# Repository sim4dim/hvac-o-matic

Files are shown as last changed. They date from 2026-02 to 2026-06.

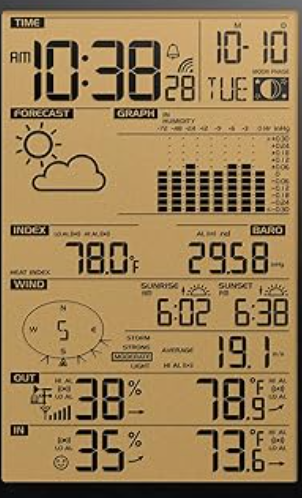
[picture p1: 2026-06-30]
screenshots/2026-05-18T20-38-01-354Z-Screenshot_2026-05-18_at_4.37.25_PM.png

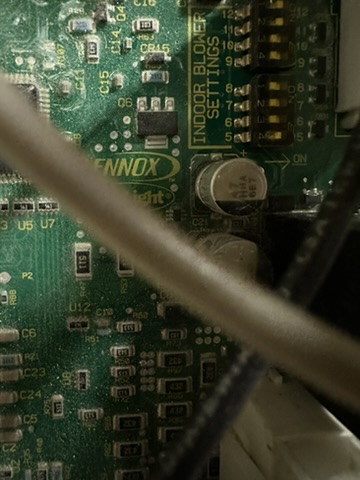
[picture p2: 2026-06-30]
screenshots/2026-06-29T21-41-32-357Z-4EC95CB4-6879-451B-B8CF-8DA977CA0F62_4_5005_c.jpeg

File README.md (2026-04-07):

# Keenect — Smart HVAC Zone Control

<!-- TODO: Add badges (HA version, ESPHome version, license) -->

Add per-room temperature control to a standard single-zone forced-air furnace using Keen Smart Vents, an ESP32 furnace controller, and Home Assistant automation logic. No HVAC contractor required.

<!-- TODO: Add screenshots -->

---

## Table of Contents

1. [Overview](#overview)
2. [System Architecture](#system-architecture)
3. [Hardware Requirements](#hardware-requirements)
4. [Software Requirements](#software-requirements)
5. [How It Works](#how-it-works)
6. [Safety Design](#safety-design)
7. [Installation](#installation)
8. [Configuration](#configuration)
9. [Project Structure](#project-structure)
10. [Legacy / History](#legacy--history)
11. [Contributing](#contributing)
12. [License](#license)

---

## Overview

Most homes have a single-zone forced-air HVAC system: one thermostat controls the whole house. Rooms with more sun exposure, different insulation, or different occupancy patterns are always too hot or too cold.

Keenect solves this by adding per-room temperature setpoints on top of your existing system without replacing the furnace or ductwork:

- **Keen Smart Vents** (Zigbee motorized dampers) control airflow into each room proportionally based on how far that room is from its setpoint.
- **An ESP32-S3 controller** with a relay board takes over from your wall thermostat to run the furnace only when one or more zones demand it.
- **Home Assistant** runs the control loop, calculates demand across all zones, and coordinates everything.
- A **hardware bypass** ensures your original thermostat retakes control if anything fails.

The system currently controls four zones (master bedroom, two kids' rooms, first floor) with additional passive temperature monitoring in other rooms.

---

## System Architecture

```
┌─────────────┐     Zigbee      ┌──────────────┐
│ Keen Vents  │◄───────────────►│ Zigbee Hub   │
│ (per room)  │                 │ (Hubitat C-8)│
└─────────────┘                 └──────┬───────┘
                                       │ Integration
┌─────────────┐     ESPHome API  ┌─────┴────────┐     MQTT        ┌──────────────┐
│ 1st Floor   │◄────────────────►│              │───heartbeat────►│ ESP32-S3     │
│ Servo (ESP32)│                 │ Home         │                 │ HVAC         │
└─────────────┘                 │ Assistant    │                 │ Controller   │
                                │              │                 │              │
┌─────────────┐                 │ Pyscript:    │                 │ 8ch Relay    │
│ Thermostats │◄───────────────►│ keenect_ha   │                 │ Board        │
│ (HA climate)│  climate_tmpl   │              │                 └──────┬───────┘
└─────────────┘                 └──────────────┘                        │ 24VAC
                                                                 ┌──────┴───────┐
                                                                 │   Furnace    │
                                                                 │ Heat/Cool/Fan│
                                                                 └──────────────┘
```

**Control flow:**

1. Each zone has an HA climate entity with its own temperature setpoint.
2. Pyscript (`keenect_ha.py`) evaluates all zones every 15 seconds.
3. If any zone demands heat or cool (temp deviates from setpoint beyond hysteresis), the script commands the ESP32 to energize the appropriate relay.
4. Vent positions are calculated proportionally — zones that need more conditioning get more airflow, satisfied zones close their vents.
5. The ESP32 publishes MQTT heartbeats to confirm HA is alive. If heartbeats stop, the ESP32 falls back to bypass mode and hands control back to the wall thermostat.

**Two ESP32 devices:**

- `hvac-controller` (ESP32-S3-WROOM-1): Main furnace relay controller with BME280/BME680 duct sensors and SSD1306 OLED display.
- `hvac-1st-floor` (Heltec WiFi Kit 32 V3): Controls a servo-driven register for the first-floor zone, with its own OLED display.

---

## Hardware Requirements

| Component | Purpose | Notes |
|---|---|---|
| ESP32-S3-WROOM-1-N16R8 | Main furnace controller | 16MB flash, 8MB PSRAM; ~$7/unit in 3-packs (AYWHP) |
| 8-channel 5V relay module | Furnace relay switching | Kootek or equivalent; active-low |
| 10K resistors (8x) | Pull-ups on relay GPIOs | Prevent relay chatter during ESP32 boot |
| BME280 (I2C) | Supply duct temperature/humidity | Monitors air coming out of furnace |
| BME680 (I2C) | Return duct temperature/humidity/VOC | Monitors air returning to furnace |
| SSD1306 128x64 OLED | Status display on controller | I2C, shared bus with sensors |
| Keen Smart Vents | Per-room airflow control | Zigbee; 1–2 per zone |
| Heltec WiFi Kit 32 V3 | 1st floor servo controller | Includes built-in OLED |
| Standard servo motor | Register damper control | Controls 1st floor supply register |
| 24VAC to 5V DC converter | Power from furnace transformer | Tap R/C wires from furnace |
| Zigbee coordinator | Keen vent radio hub | Hubitat C-8 used here; any coordinator works |
| Pearl thermostat | Bypass / fallback thermostat | Stays wired in; takes over if ESP32 fails |

**Wiring note:** The relay board requires 10K pull-up resistors from each relay GPIO to 3.3V. Without them, GPIOs float low during boot and the relays fire briefly — causing spurious furnace activation on every reboot.

---

## Software Requirements

### Home Assistant
- Home Assistant (any recent release)
- **Pyscript** integration (`allow_all_imports: true`)
- **HACS** with:
  - [`climate_template`](https://github.com/jcwillox/hass-template-climate) — provides per-zone climate entities with custom temperature sensors
  - [`fold-entity-row`](https://github.com/thomasloven/lovelace-fold-entity-row) — collapsible settings rows in the dashboard

### ESPHome
- ESPHome (any recent release)
- MQTT broker on the local network (no authentication required by default)

### Optional
- Hubitat Elevation hub (for Zigbee radio if not using a dedicated Zigbee coordinator)

---

## How It Works

### Zone evaluation

Every 15 seconds, pyscript evaluates each zone:

1. Read the zone's current temperature from its dedicated sensor.
2. Compare against the active setpoint (heat or cool depending on HVAC mode).
3. If the deviation exceeds the hysteresis threshold, the zone is "demanding."
4. Calculate a vent opening percentage proportional to how much conditioning is needed.

### HVAC demand aggregation

After evaluating all zones:

- If any zone is demanding heat, and the system is in heat mode: turn on heat.
- If no zones demand heat: turn off heat (after the vent closure delay).
- Same logic applies for cool mode.
- A global `input_select.hvac_mode` drives heat vs. cool across all zones simultaneously.

### Vent positioning

Keen Smart Vents are controlled via Zigbee as `light` entities — `light.turn_on(brightness_pct=N)` sets the vent to N% open. The first-floor zone uses a servo register exposed as a `number` entity via ESPHome.

Vent control modes:
- **Demanding zones**: open proportionally (min_vo to max_vo range)
- **Satisfied zones**: close to min_vo (never fully closed — prevents duct overpressure)
- **Fan circulation**: all zones open to `fan_vo`
- **Vent closure delay**: 120 seconds after heat turns off before vents close (furnace spin-down is ~110 seconds; closing early causes overpressure)

### Heartbeat watchdog

Pyscript publishes an MQTT heartbeat every 60 seconds to `keenect/heartbeat`. The ESP32 monitors this topic. If no heartbeat is received for 5 minutes, the ESP32 de-energizes the changeover relays, returning the Pearl thermostat to direct control of the furnace. This covers the failure mode where HA is running but pyscript has crashed.

---

## Safety Design

**This system controls a gas furnace. Incorrect wiring or software bugs can damage equipment, void warranties, or cause fires. Read this section carefully before installation.**

### Hardware bypass (fail-safe)

The relay board uses a changeover relay architecture:

- **Relays 5, 6, 7** are changeover relays (SPDT) wired between the furnace terminals (W/Y/G) and both the Pearl thermostat (NC) and the ESP32 control relays (NO).
- When the changeover relays are **de-energized** (NC position), the Pearl thermostat controls the furnace directly. This is the default state.
- When the changeover relays are **energized** (NO position), the ESP32 relays control the furnace. Pearl is powered but disconnected.
- If the ESP32 loses power or crashes, all relays de-energize. The furnace falls back to Pearl thermostat control. **No code required — this is a hardware property.**

### Bypass modes

| Condition | Behavior |
|---|---|
| ESP32 boots normally | Stays in bypass until HA API connects |
| HA API connects | Exits bypass (unless physical toggle switch is set) |
| HA API disconnects | 60-minute bypass watchdog timer starts |
| Pyscript heartbeat lost (5 min) | Enters bypass immediately |
| Physical bypass switch pressed | Enters bypass regardless of software state |
| Manual bypass command from HA | Enters bypass |

### Short-cycle protection

- **Compressor**: minimum 5 minutes between cool-off and cool-on (refrigerant equalization)
- **Heat exchanger**: minimum 2 minutes between heat-off and heat-on

### Other safety features

- **Max-run timer**: If heat or cool runs continuously for 2 hours, the ESP32 forces bypass and publishes an alert to `hvac/errors`.
- **Supply temperature limit**: If the BME280 reads supply air above 160°F during heating, heat shuts off immediately (Lennox G61MPV heat exchanger limit).
- **Vent closure delay**: 120 seconds after furnace turns off before vents close. Prevents overpressure during furnace blower spin-down (~110 seconds).
- **MQTT error alerts**: All fault conditions publish to `hvac/errors`.

---

## Installation

### 1. Flash the ESP32 firmware

Copy `esphome/secrets.yaml.example` to `esphome/secrets.yaml` and fill in your Wi-Fi credentials, API key, and OTA password.

```bash
esphome run esphome/hvac-controller.yaml
esphome run esphome/hvac-1st-floor.yaml
```

### 2. Wire the relay board

Follow the wiring diagram in `esphome/hvac-controller.yaml` (lines 12–99). Key points:

- Add 10K pull-up resistors from each relay GPIO (4, 5, 6, 7, 15, 16, 17, 18) to 3.3V.
- Relays 5, 6, 7 are changeover relays — wire NC terminals to the Pearl thermostat outputs and NO terminals to the ESP32 control relay outputs (relays 1, 2, 3).
- Power the relay board from a 24VAC-to-5V converter tapped from the furnace R/C terminals.

### 3. Deploy HA configuration

Copy the package files to `/config/packages/` on your HA instance:

```bash
scp ha/packages/keenect.yaml     hassio@<HA_IP>:/config/packages/
scp ha/packages/thermostats.yaml hassio@<HA_IP>:/config/packages/
```

Deploy the pyscript file:

```bash
scp ha/pyscript/keenect_ha.py hassio@<HA_IP>:/config/pyscript/
```

Deploy the dashboard:

```bash
scp ha/dashboards/keenect.yaml hassio@<HA_IP>:/config/dashboards/
```

Restart Home Assistant to load the packages and pyscript.

### 4. Install HACS components

In HACS, install:
- `climate_template` by jcwillox
- `fold-entity-row` by thomasloven

### 5. Create the persisted state helper

The pyscript uses a long-lived `input_text` entity that must be created via the HA WebSocket API (not YAML, to survive config reloads):

In HA Settings > Helpers, create an Input Text named `keenect_persisted_state` with max length 255.

### 6. Enable Keenect

Keenect starts **disabled** by default. Once wiring is verified and all zones are reporting temperatures, enable it:

- In HA: toggle `input_boolean.keenect_enabled` to ON.
- Verify that the furnace responds to a zone demand (raise a setpoint above current room temp in heat mode).

> **Critical**: Always verify the furnace responds to demand after any configuration change. Silent failures can leave the house without heat.

---

## Configuration

### Zone settings

Zones are defined in `ha/pyscript/keenect_ha.py` in the `_HARDCODED_ZONES` dict. Each zone specifies:

```python
"ben": {
    "thermostat": "climate.ben_s_room",    # HA climate entity
    "temp_sensor": "sensor.gw1000_temp_ch7",  # raw temperature sensor
    "vents": ["light.keen_ben"],            # Keen vent entity (or servo number)
    "vent_type": "light",                   # "light" for Keen, "number" for servo
    "health_sensors": ["sensor.keen_ben_pressure"],
    "heat_min_vo": 15, "heat_max_vo": 100, # vent % range during heat
    "cool_min_vo": 15, "cool_max_vo": 100, # vent % range during cool
    "fan_vo": 30,                           # vent % during circulation-only
    "vent_control": "Aggressive",
},
```

For a servo-based zone (first floor), `vent_type` is `"number"` and the min/max values are servo angles in degrees (max 45°).

### Adjustable parameters (HA helpers)

| Helper | Default | Description |
|---|---|---|
| `input_number.keenect_hysteresis` | 1.0°F | Dead band around setpoint before demanding |
| `input_number.vent_closure_delay` | 120s | Delay before closing vents after furnace off |
| `input_number.cool_lockout_temp` | 65°F | Outdoor temp below which cooling is locked out |
| `input_select.hvac_mode` | heat | Global mode: heat / cool / fan / off |
| `input_boolean.keenect_enabled` | off | Master enable switch |

### Thermostat entities

Each zone uses a `climate_template` entity defined in `ha/packages/thermostats.yaml`. The template reads setpoints from `input_number` helpers and publishes temperature from the zone's dedicated sensor. This keeps the display thermostat UI working while pyscript handles all the logic underneath.

---

## Project Structure

```
hvac/
├── ha/
│   ├── pyscript/
│   │   └── keenect_ha.py          # Main HVAC zone control logic (v2.5.0)
│   ├── packages/
│   │   ├── keenect.yaml           # Input helpers and sensors
│   │   ├── keenect_zones.yaml     # Zone configuration
│   │   └── thermostats.yaml       # Climate entity definitions
│   └── dashboards/
│       └── keenect.yaml           # Lovelace dashboard
├── esphome/
│   ├── hvac-controller.yaml       # ESP32-S3 furnace controller
│   ├── hvac-1st-floor.yaml        # 1st floor servo register controller
│   ├── hvac-spare.yaml            # Spare board config
│   └── secrets.yaml.example       # Secrets template
├── hubitat/                       # Legacy Hubitat drivers (historical reference)
│   ├── KeenectLiteMaster.groovy
│   ├── KeenectLiteZone.groovy
│   └── ...
├── 3d/
│   └── hvac-controller-enclosure.scad  # 3D-printable controller enclosure
├── backups/                       # Legacy implementations
├── check_drift.py                 # Temperature sensor drift analysis tool
├── torture_test.sh                # ESP32 relay stress test
└── screenshots/                   # Dashboard screenshots
```

### Key files

- **`ha/pyscript/keenect_ha.py`** — All zone control logic: demand calculation, vent positioning, HVAC command dispatch, anomaly detection, cost tracking.
- **`esphome/hvac-controller.yaml`** — ESP32-S3 firmware with full wiring diagram, relay assignments, bypass logic, MQTT watchdog, and duct sensor processing.
- **`esphome/hvac-1st-floor.yaml`** — Heltec-based servo controller for the first-floor register.
- **`ha/packages/thermostats.yaml`** — Four `climate_template` entities, one per zone.
- **`3d/hvac-controller-enclosure.scad`** — OpenSCAD source for a 3D-printable DIN-rail enclosure sized for the ESP32-S3 + relay board.

---

## Legacy / History

Keenect originated as a Hubitat Elevation app — `KeenectLiteMaster` + `KeenectLiteZone` (Groovy). These are retained in `hubitat/` for historical reference.

The system was migrated to Home Assistant + pyscript to gain richer automation capabilities, better sensor integration (Ecowitt GW1000 weather gateway), and ESPHome-based hardware control. The Hubitat C-8 hub is still used as a Zigbee radio for the Keen vents, accessed through the Hubitat integration.

The original furnace controller was a Raspberry Pi running a Flask HTTP server (e.g., `192.168.1.123:5000` — legacy address, configure for your network). This is being replaced by the ESP32-S3 relay board described in this README.

---

## Contributing

This is a personal home automation project shared for reference. If you adapt it for your own system, keep the safety architecture intact:

- Keep the changeover relay bypass wired with NC to the fallback thermostat.
- Do not remove the heartbeat watchdog.
- Test furnace response after every code change before leaving the house.

Issues and pull requests are welcome for bugs, documentation improvements, or hardware variations.

---

## License

MIT License. See `LICENSE` for details.

This software controls physical heating and cooling equipment. The authors are not responsible for equipment damage, property damage, or any other harm resulting from its use. Use at your own risk. Always maintain a working fallback thermostat.

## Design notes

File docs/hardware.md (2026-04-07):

# HVAC Hardware Documentation

## 1. HVAC Controller (ESP32-S3)

### Board

**MCU**: ESP32-S3-WROOM-1-N16R8 on a Freenove ESP32-S3 Breakout Board
- 16MB flash, 8MB PSRAM (octal mode, 80MHz)
- ESPHome firmware: `esphome/hvac-controller.yaml`
- Network: e.g., `hvac-controller.local` (configure hostname and IP for your network)

**Relay Board**: Kootek 8-Channel 5V Relay Module (active-low)
- Requires 10K pull-up resistors from each relay GPIO to 3.3V
- Without pull-ups, GPIOs float LOW during boot and relays fire briefly, causing spurious furnace activation

### GPIO Pin Map

| GPIO | Function | Relay | Notes |
|---|---|---|---|
| 4 | Heat (W) | 1 | 24VAC to furnace W terminal |
| 5 | Cool (Y) | 2 | 24VAC to furnace Y terminal |
| 6 | Fan (G) | 3 | 24VAC to furnace G terminal |
| 7 | UV Light | 4 | On when any airflow active |
| 15 | W Changeover | 5 | NC=Pearl, NO=ESP32 |
| 16 | Y Changeover | 6 | NC=Pearl, NO=ESP32 |
| 17 | G Changeover | 7 | NC=Pearl, NO=ESP32 |
| 18 | Spare | 8 | Internal, unused |
| 11 | Bypass Switch | - | INPUT_PULLUP, physical toggle |
| 10 | Warning LED | - | On during bypass mode |
| 48 | RGB LED | - | WS2812 onboard status LED |
| 8 | I2C SDA | - | 100kHz |
| 9 | I2C SCL | - | 100kHz |

**Avoided GPIOs**: 0, 3, 19-20, 26-32, 45, 46 (PSRAM/flash lines, strapping pins, USB)

### Pull-Up Wiring

```
3.3V ──┬──┬──┬──┬──┬──┬──┬──
       R  R  R  R  R  R  R  R    (10K each)
       │  │  │  │  │  │  │  │
       4  5  6  7 15 16 17 18    (GPIO -> relay board IN1-IN8)
```

### I2C Devices

| Address | Device | Location | Measures |
|---|---|---|---|
| 0x76 | BME280 | Supply duct | Temperature, humidity, pressure |
| 0x77 | BME680 | Return duct | Temperature, humidity, pressure, VOC |
| 0x3C | SSD1306 | Enclosure front | 128x64 OLED display |

### 24VAC Thermostat Wiring

```
FURNACE                  RELAY BOARD                   PEARL THERMOSTAT
───────                  ───────────                   ────────────────

R (24V hot) ─────┬───────────────────────────────────── R
                 │
                 ├── Relay 1 COM ── NO ──> Relay 5 NO
                 ├── Relay 2 COM ── NO ──> Relay 6 NO
                 └── Relay 3 COM ── NO ──> Relay 7 NO

W (heat) ──────────── Relay 5 COM
                          NC <─────────────────────────── W
                          NO <── Relay 1 output

Y (cool) ──────────── Relay 6 COM
                          NC <─────────────────────────── Y
                          NO <── Relay 2 output

G (fan) ───────────── Relay 7 COM
                          NC <─────────────────────────── G
                          NO <── Relay 3 output

C (common) ──────────────────────────────────────────── C
```

### Bypass Architecture

```
                    ┌─────────────────┐
Pearl Thermostat ──>│ Changeover      │──> Furnace
                    │ Relays 5-7      │
ESP32 Relays 1-3 ──>│ (NC=Pearl,      │
                    │  NO=ESP32)      │
                    └─────────────────┘
```

**Normal mode** (changeover relays 5-7 energized, NO position): ESP32 relays 1-3 control the furnace W, Y, G lines. Pearl is powered via R and C but disconnected from furnace outputs.

**Bypass mode** (changeover relays 5-7 de-energized, NC position): Pearl thermostat controls the furnace directly. ESP32 control relays 1-3 are irrelevant — they are electrically disconnected from the furnace.

**Fail-safe** (ESP32 dead or unpowered): All relays de-energize to NC by default. Pearl resumes control automatically. No code required — this is a hardware property of the relay module.

Bypass is triggered by:
- Physical toggle switch on GPIO11
- HA command via ESPHome API
- 60-minute API watchdog (no HA connection)
- 5-minute keenect MQTT heartbeat watchdog
- Safety limits: 2-hour max run, supply temp > 160F, pressure delta > 10 hPa

### RGB Status LED (GPIO48)

| Color | State |
|---|---|
| Green solid | Normal, idle |
| Red solid | Heat active |
| Blue solid | Cool active |
| Purple solid | Bypass active |
| Orange flashing | Watchdog bypass |

### Power

24VAC from furnace transformer -> 24VAC-to-5VDC converter -> powers ESP32 and relay board.

---

## 2. 1st Floor Servo Controller (Heltec WiFi Kit 32 V3)

**Board**: Heltec WiFi Kit 32 V3 (ESP32)
- ESPHome firmware: `esphome/hvac-1st-floor.yaml`
- Static IP: `192.168.1.63` (configure for your network)
- Controls the first-floor supply register via a servo motor

### GPIO Pin Map

| GPIO | Function | Notes |
|---|---|---|
| 46 | Servo PWM | 50Hz LEDC output, auto-detach after 3s |
| 17 | I2C SDA | 400kHz |
| 18 | I2C SCL | 400kHz |
| 21 | OLED Reset | SH1106 128x64 display |

### Servo

- Range: 0 to 45 degrees
- 0 = closed, 45 = fully open
- ESPHome level mapping: `level = (angle / 90.0) - 1.0` (maps 0-45 into the -1.0 to -0.5 servo range)
- Auto-detach after 3 seconds to reduce servo heat and current draw
- Transition length: 2 seconds

### Display

- Model: SH1106 128x64 OLED at I2C address 0x3C
- Screensaver mode (most of the time): shows current angle at a randomized position to prevent burn-in
- Full info mode (5 seconds every 30 seconds): shows IP address and servo angle

---

## 3. Keen Smart Vents

- Protocol: Zigbee, paired to Hubitat C-8 coordinator
- Exposed in Home Assistant as `light.*` entities (NOT `cover.*`)
- Control: brightness percentage maps to vent opening (0% = closed, 100% = fully open)
- Entity IDs: `light.keen_ben`, `light.keen_gene`, `light.keen_mbr_1`, `light.keen_mbr_2`
- Note: the physical vent mechanism may not reach exactly 0% when commanded off; treat the commanded value as a target, not a guarantee

---

## 4. 3D Printed Enclosure

OpenSCAD file: `3d/hvac-controller-enclosure.scad`

Designed to hold:
- Freenove ESP32-S3 Breakout Board (87.6 x 83.2 x 22mm)
- Kootek 8-Channel Relay Module (139 x 56 x 19mm)
- TCA9548A I2C Multiplexer Hub (31.5 x 21.4 x 7mm)
- 0.96" SSD1306 OLED Display on front panel
- 12mm bypass button on front panel
- 5mm warning LED on front panel

Interior layout (relay terminals face the open/right side):

```
+-----------------------------------------------+
|  Relay Module (139 x 56)       [terminals] -->  (open right side)
|                                               |
|-----------------------------------------------|
|  Freenove Breakout (87.6 x 83.2) | I2C Hub   |
|                                   | (corner)  |
+-----------------------------------------------+
```

Wall mount: 4 keyhole slots on the back panel (2 top, 2 bottom), accepts standard screw heads up to 8mm diameter.

**Important**: Verify that the OpenSCAD dimensions match your specific board revisions before printing. Board dimensions vary between manufacturers and batches. Adjust the parametric variables at the top of the file as needed.

---

## 5. Safety Wiring Notes

- Use appropriate wire gauge for 24VAC connections (18 AWG minimum recommended for thermostat wiring runs).
- The changeover relay architecture is inherently fail-safe: a dead or unpowered ESP32 leaves all relays de-energized, which places them in the NC position, restoring Pearl thermostat control automatically.
- Mount the controller in an accessible location near the furnace for easy bypass switch access.
- Ensure adequate ventilation around the relay board — the relay coils generate heat under sustained load.
- **10K pull-up resistors on relay GPIOs are required.** Without them, GPIOs float during boot and the relays will briefly energize, potentially sending spurious heat or cool commands to the furnace on every restart.
- Short-cycle protections are enforced in firmware: heat is blocked for 120 seconds after the previous off event; cool is blocked for 300 seconds. These protect the furnace and compressor from rapid cycling.
- Supply temperature high limit (160F) and pressure delta limit (10 hPa) will force bypass and shut off outputs if exceeded.

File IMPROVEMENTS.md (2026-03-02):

# HVAC Improvement Plan

Status: PENDING — waiting for ESPHome controller to be housed and physically installed.

## Context

This plan was generated from a multi-agent code review (Feb 2024) where an Architect agent (code quality focus) and Operator agent (safety/ops focus) independently reviewed the codebase, then debated priorities over MQTT. The Flask server at 192.168.1.123:5000 is the legacy furnace controller being actively replaced by the ESPHome ESP32-S3 controller. These improvements are for AFTER the migration, targeting gaps that exist regardless of transport layer.

## Priority 1: ESPHome Hardware Safety Layer

**Problem:** The ESPHome controller has zero runtime safety protections. Relays can stay energized indefinitely once turned on via API. If HA, pyscript, or the network dies, the furnace runs unchecked until the 60-minute API watchdog trips bypass — or forever if HA is up but pyscript is dead.

**File:** `esphome/hvac-controller.yaml`

**Changes needed:**

### 1a. Max-run timer (2 hour auto-off)
Add an `interval` block that tracks how long `heat_sw` or `cool_sw` has been continuously ON. If either exceeds 120 minutes, force all relays off, enter bypass mode, publish MQTT alert to `hvac/errors`.

### 1b. Short-cycle protection (compressor-safe)
Track last relay-off timestamp. Refuse to re-energize `cool_sw` within 5 minutes of last off (compressor refrigerant equalization). Refuse to re-energize `heat_sw` within 2 minutes of last off (heat exchanger thermal stress). Log blocked attempts.

### 1c. Supply temperature bounds
The BME280 reads supply air temp but nothing acts on it. Add:
- **High limit:** If supply temp > 160F while heating, immediately shut off heat relay + alert. (Lennox G61MPV heat exchanger limit.)
- **Low limit:** If supply temp < 80F after 10 minutes of continuous heating, alert for probable igniter/gas failure. Don't shut off (the furnace's own safety handles that) but notify.

### 1d. Duct pressure delta safety
The `pressure_delta` sensor exists but nothing acts on it. If differential pressure exceeds a threshold (TBD, needs baseline measurement) while furnace is running, shut off to prevent overpressure from closed vents. This is a backup to the 120-second vent closure delay.

**Why this is #1:** This is the ONLY safety layer that works when all software above it (HA, pyscript, network) has failed. Defense in depth.

## Priority 2: Pyscript-to-ESPHome Heartbeat Watchdog

**Problem:** The current ESPHome watchdog (line ~189) only checks API connectivity. If Home Assistant is running but pyscript has crashed, OOM'd, or failed to load, the watchdog sees a healthy API connection and never trips bypass. The furnace stays in whatever state pyscript last commanded — potentially running heat/cool indefinitely with no software oversight.

**Files:** `ha/pyscript/keenect_ha.py` + `esphome/hvac-controller.yaml`

**Changes needed:**

### 2a. Pyscript heartbeat publisher
In `keenect_ha.py`, add a `@time_trigger("period(now, 60s)")` function that publishes to MQTT topic `keenect/heartbeat` via `task.executor`. This confirms pyscript is alive and running periodic evaluations.

### 2b. ESPHome heartbeat subscriber
In `hvac-controller.yaml`, subscribe to `keenect/heartbeat` via MQTT. Reset a counter on each received message. If 5 consecutive heartbeats are missed (5 minutes), enter bypass mode (de-energize changeover relays, Pearl thermostat resumes control). Publish alert to `hvac/errors`.

### 2c. Replace or supplement the 60-minute API watchdog
The current 60-minute timeout (line ~189) is too long for a sole controller. Either:
- Reduce to 15 minutes as a fallback, OR
- Let the heartbeat watchdog (5 min) be the primary, keep API watchdog as secondary at 15 min.

**Why this is #2:** Covers the critical "HA alive, pyscript dead" failure mode that the current watchdog completely misses.

## Priority 3: Fix `_hvac_push` Failure Cascade

**Problem:** `_hvac_turn_on()` (lines ~506-518) and `_hvac_turn_off()` (lines ~524-536) in `keenect_ha.py` call `_hvac_push()` but ignore its boolean return value. If push fails (Flask/ESPHome unreachable), pyscript sets `main_state = "HEATING"` and `hvac_on = True` anyway. This creates a phantom state: software thinks furnace is on, but it's off (or vice versa). Zones never satisfy, anomaly detection fires 10+ minutes later at best, and the system is blind.

**File:** `ha/pyscript/keenect_ha.py`

**Changes needed:**

### 3a. Check return values
In `_hvac_turn_on()` and `_hvac_turn_off()`, check the return value of each `_hvac_push()` call. If any returns `False`, do NOT update `_st["main_state"]`, `_st["hvac_on"]`, or any other state variables. Return early and let the next eval cycle retry.

### 3b. Failure counter with escalating alerts
Add `_st["push_fail_count"]`. Increment on each failed push, reset on success.
- After 3 consecutive failures: create a `persistent_notification` in HA.
- After 5 consecutive failures: auto-disable keenect by turning off `input_boolean.keenect_enabled`. This prevents the system from continuing to operate with a broken control path.

### 3c. Sensor death alerting (related)
`_eval_zone()` returns `None` when a temperature sensor is unavailable (line ~744). The zone is silently skipped in `_eval_master()`. Add:
- Track consecutive `None` returns per zone in `_st["sensor_fail_count"]`.
- Alert after 3 consecutive failures (~45 seconds at 15s eval).
- Move zone vents to neutral position after 10 failures.
- If ALL 4 zones return `None` simultaneously: emergency shutoff + alert (probable Ecowitt GW1000 gateway failure).

## Secondary Items (lower priority, do when convenient)

### S1. Startup race condition
`on_startup()` (line ~1209) sets `hvac_on=False` but doesn't send off commands until after `_eval_master()` runs. If eval turns furnace on, then the safety sync sends off commands. Fix: send unconditional off commands BEFORE eval, in a `finally` block.

### S2. Startup Zigbee delay
After power outage, Keen vents need 60-90 seconds to rejoin the mesh. Commands sent during this window are silently dropped. Add a startup delay before first eval, or a verification pass 2 minutes after startup.

### S3. Cost tracking persistence
`_st["heat_runtime"]` and `_st["heat_cost"]` reset to 0 on every pyscript reload. Replace with HA `utility_meter` on a `binary_sensor.hvac_active`.

### S4. ESPHome changeover relay settle time
No delay between energizing changeover relays and first control command. Add 200ms settle delay in `bypass_sw.turn_off_action`.

### S5. Warmup sensor staleness
`_is_warming_up()` silently falls back to 120s fixed delay when duct sensors are offline. No alert that sensors aren't contributing. Add diagnostic attribute.

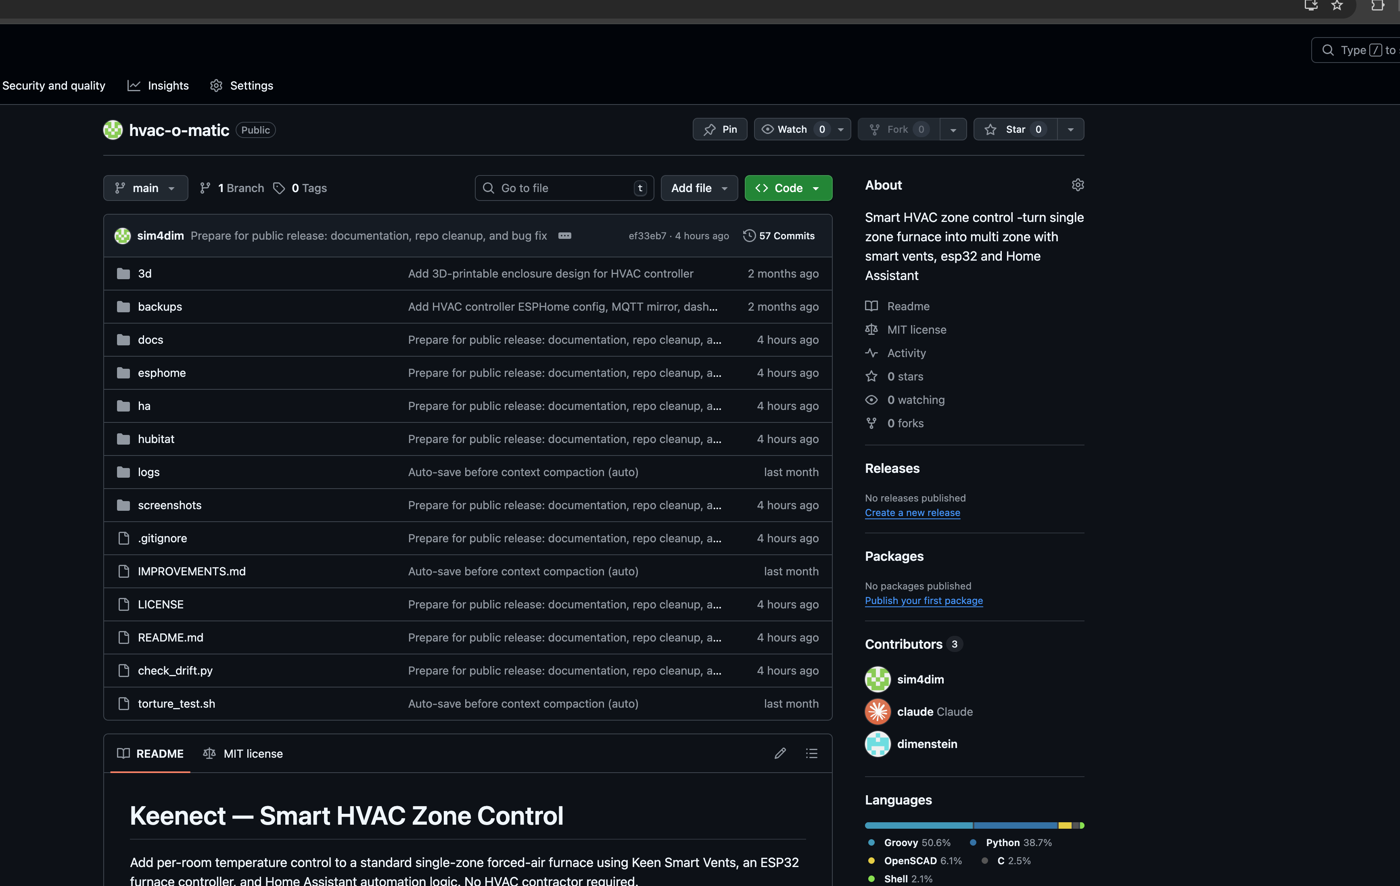
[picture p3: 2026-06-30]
screenshots/2026-04-07T20-57-09-542Z-Screenshot_2026-04-07_at_4.56.51_PM.png

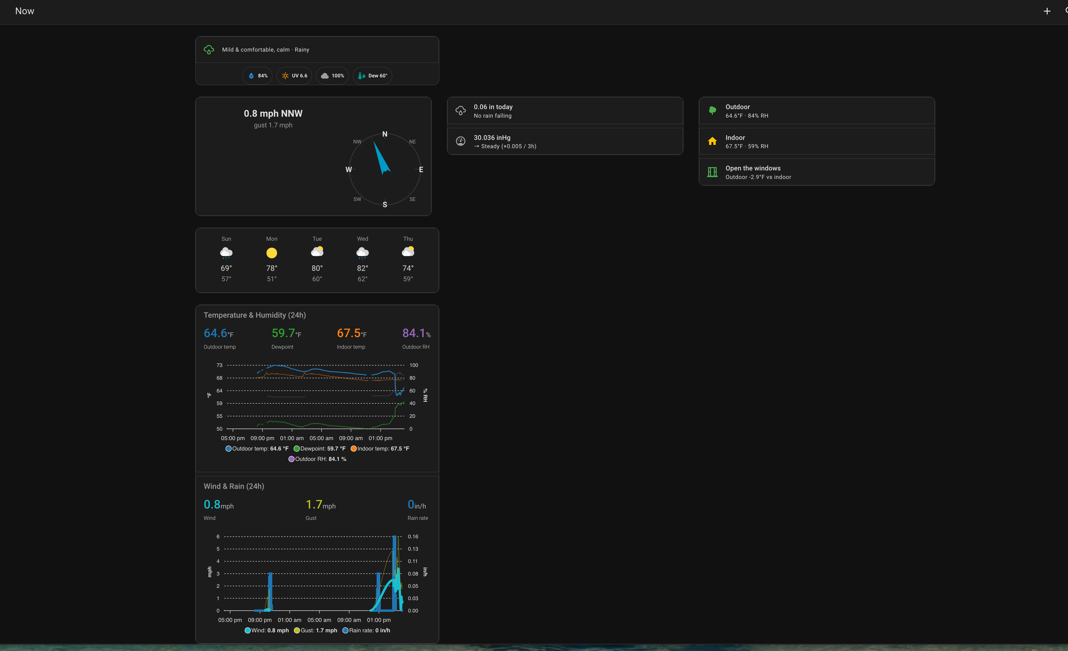
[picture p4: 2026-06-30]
screenshots/2026-05-24T20-17-42-172Z-Screenshot_2026-05-24_at_4.15.07_PM.png

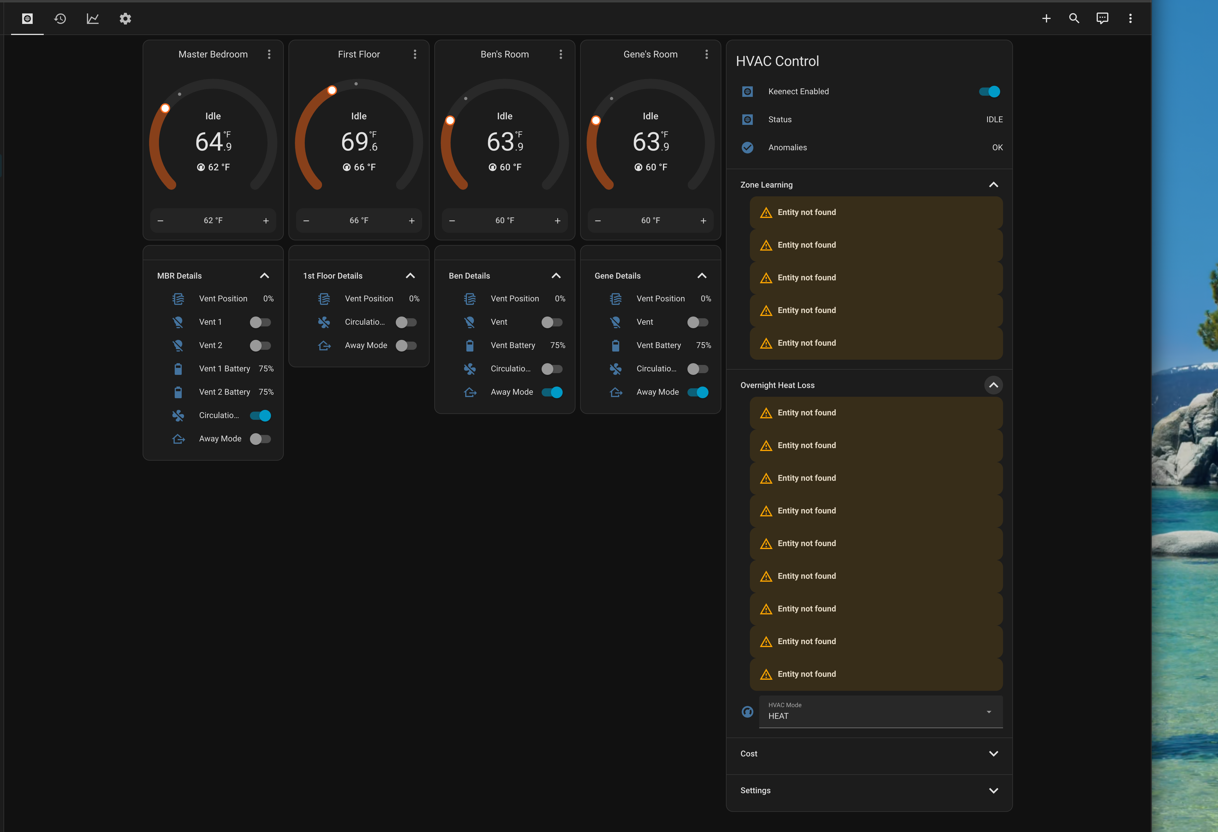
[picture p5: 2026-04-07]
screenshots/2026-03-14T18-06-08-068Z-Screenshot_2026-03-14_at_2.05.13_PM.png

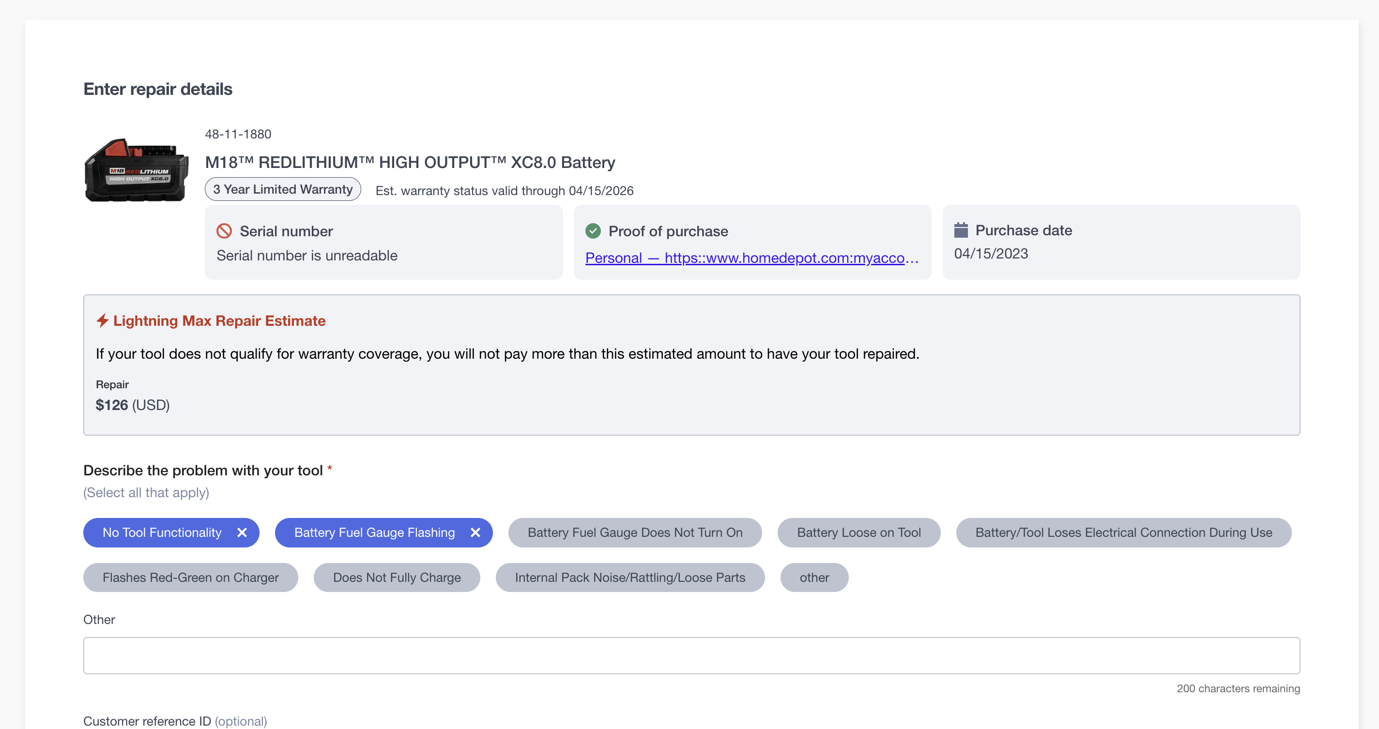
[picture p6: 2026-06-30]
screenshots/2026-05-24T20-15-22-226Z-Screenshot_2026-04-29_at_11.56.30_AM.png

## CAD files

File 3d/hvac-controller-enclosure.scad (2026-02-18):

// ============================================================================
// HVAC Controller Enclosure - Wall-Mountable
// ============================================================================
// Parametric enclosure for:
//   - Freenove ESP32-S3 Breakout Board
//   - Kootek 8-Channel Relay Module
//   - TCA9548A I2C Multiplexer Hub
//   - 0.96" SSD1306 OLED Display (front panel)
//   - 12mm Bypass Button (front panel)
//   - 5mm Warning LED (front panel)
//
// Usage:
//   Set `part` to "base", "lid", or "both" to render each piece.
//   Adjust `tolerance` for your printer's fit.
// ============================================================================

// --- Part Selector ---
part = "both";  // "base", "lid", or "both"

// --- Global Settings ---
$fn = 30;
tolerance = 0.3;       // Printer tolerance for fits

// --- Wall & Structure ---
wall = 2.5;            // Wall thickness (mm)
corner_r = 3;          // Corner radius for printability
standoff_h = 6;        // Standoff height above base floor
standoff_base_d = 8;   // Standoff base diameter for stability
standoff_top_d = 6;    // Standoff top (pillar) diameter
screw_hole_d = 3.2;    // M3 through-hole diameter
board_gap = 8;         // Gap between boards for airflow/wiring

// --- Component Dimensions (L x W x H) ---
// Freenove ESP32-S3 Breakout
freenove_l = 87.6;
freenove_w = 83.2;
freenove_h = 22;
freenove_mount_l = 81;   // Hole center-to-center X
freenove_mount_w = 77;   // Hole center-to-center Y
freenove_hole_d = 3.2;

// Kootek 8-Channel Relay Module
relay_l = 139;
relay_w = 56;
relay_h = 19;
relay_mount_l = 132;     // Hole center-to-center X
relay_mount_w = 50;      // Hole center-to-center Y
relay_hole_d = 3.1;

// TCA9548A I2C Hub
i2c_l = 31.5;
i2c_w = 21.4;
i2c_h = 7;
i2c_hole_d = 3.0;       // M3
// Diagonal mounting: 2 holes at opposite corners
i2c_mount_diag_x = 25;  // Approximate diagonal hole spacing X
i2c_mount_diag_y = 15;  // Approximate diagonal hole spacing Y

// SSD1306 OLED Display
oled_l = 27;
oled_w = 27;
oled_h = 3.5;
oled_mount_l = 23.5;    // Hole center-to-center X
oled_mount_w = 23.5;    // Hole center-to-center Y
oled_hole_d = 3.0;      // M3
oled_view_l = 22;       // Visible display area width
oled_view_w = 11;       // Visible display area height

// 12mm Bypass Button
button_bezel_d = 14;
button_depth = 25;
button_cutout_d = 12;

// 5mm Warning LED
led_d = 5;
led_hole_d = 5.5;

// --- Enclosure Interior Layout ---
// Layout strategy (viewed from above, relay terminals face the right/open side):
//
//   +-----------------------------------------------+
//   |  Relay Module (139 x 56)         [terminals]-->  (open side, right)
//   |                                               |
//   |-----------------------------------------------|
//   |  Freenove Breakout (87.6 x 83.2) | I2C Hub   |
//   |                                   | (corner)  |
//   +-----------------------------------------------+
//
// Interior width  = relay_l (longest piece, along X)
// Interior depth  = relay_w + board_gap + freenove_w (along Y)

interior_l = relay_l + 2 * board_gap;
interior_w = relay_w + board_gap + freenove_w + 2 * board_gap;
interior_h_base = max(relay_h, freenove_h, i2c_h) + standoff_h + 5; // Extra clearance above tallest component

// Total exterior
ext_l = interior_l + 2 * wall;
ext_w = interior_w + 2 * wall;
ext_h_base = interior_h_base + wall;  // Base box height (no lid)

// Lid dimensions
lid_h = 8;             // Lid total height (lip + top panel)
lid_lip = 4;           // Lip that inserts into the base
lid_lip_clearance = tolerance;

// --- Lid Screw Tabs ---
lid_tab_screw_d = 3.2;    // M3 screw hole in tabs
lid_tab_w = 12;            // Tab width
lid_tab_h = 10;            // Tab height (extends below lid edge)
num_lid_tabs = 6;          // 2 per long side, 1 per short side

// --- Wall Mount Keyholes ---
keyhole_large_d = 8;      // Large end (screw head)
keyhole_small_d = 4.5;    // Narrow slot (screw shaft)
keyhole_slot_len = 8;     // Slot length
keyhole_depth = 2.5;      // Recess depth into back wall
// 4 keyholes: 2 top, 2 bottom on the back
keyhole_inset_x = 30;     // Distance from side edges
keyhole_inset_y = 20;     // Distance from top/bottom edges

// --- Vent Slots ---
vent_slot_l = 20;         // Length of each vent slot
vent_slot_w = 2;          // Width of each vent slot
vent_spacing = 5;         // Spacing between slots
vent_count_side = 4;      // Number of vent slots per side panel

// --- Cable Entry ---
cable_slot_w = 12;        // Width of cable entry slot
cable_slot_h = 8;         // Height of cable entry slot
cable_slot_count = 3;     // Number of cable entry slots on bottom

// --- Front Panel Layout ---
// OLED, button, and LED positions on the lid (X, Y from lid center)
// OLED centered horizontally, upper area of lid
oled_pos_x = 0;
oled_pos_y = interior_w / 4;

// Button to the left of OLED
button_pos_x = -ext_l / 4;
button_pos_y = interior_w / 4;

// LED to the right of OLED
led_pos_x = ext_l / 4;
led_pos_y = interior_w / 4;


// ============================================================================
// MODULES
// ============================================================================

// --- Rounded Rectangle (2D) ---
module rounded_rect_2d(l, w, r) {
    offset(r = r) offset(delta = -r)
        square([l, w], center = true);
}

// --- Rounded Box (hollow, open top) ---
module rounded_box(l, w, h, wall_t, r) {
    difference() {
        // Outer shell
        linear_extrude(height = h)
            rounded_rect_2d(l, w, r);
        // Inner cavity
        translate([0, 0, wall_t])
            linear_extrude(height = h)
                rounded_rect_2d(l - 2 * wall_t, w - 2 * wall_t, max(r - wall_t, 0.5));
    }
}

// --- Standoff with through-hole ---
module standoff(h, base_d, top_d, hole_d) {
    difference() {
        union() {
            // Wide base for stability
            cylinder(d = base_d, h = h * 0.3);
            // Narrower pillar
            cylinder(d = top_d, h = h);
        }
        // Through-hole
        translate([0, 0, -0.1])
            cylinder(d = hole_d, h = h + 0.2);
    }
}

// --- Keyhole (for wall mounting, cut into back wall) ---
module keyhole(large_d, small_d, slot_len, depth) {
    // Large circle at bottom
    translate([0, 0, -0.1])
        cylinder(d = large_d, h = depth + 0.2);
    // Slot going upward
    translate([0, 0, -0.1])
        hull() {
            cylinder(d = small_d, h = depth + 0.2);
            translate([0, slot_len, 0])
                cylinder(d = small_d, h = depth + 0.2);
        }
}

// --- Vent Slot Array (cut into a side wall) ---
module vent_slots(count, slot_l, slot_w, spacing) {
    total_h = count * slot_w + (count - 1) * spacing;
    for (i = [0 : count - 1]) {
        translate([0, 0, -total_h / 2 + i * (slot_w + spacing)])
            cube([slot_l, wall + 0.2, slot_w], center = true);
    }
}

// --- Board Mounting Holes (4 corners pattern) ---
module board_mount_holes(mount_l, mount_w, hole_d, depth) {
    for (dx = [-1, 1], dy = [-1, 1]) {
        translate([dx * mount_l / 2, dy * mount_w / 2, 0])
            cylinder(d = hole_d, h = depth, center = true);
    }
}

// --- Lid Screw Boss (on base wall, for lid attachment) ---
module lid_screw_boss(d_outer, d_hole, h) {
    difference() {
        cylinder(d = d_outer, h = h);
        translate([0, 0, -0.1])
            cylinder(d = d_hole, h = h + 0.2);
    }
}


// ============================================================================
// BASE ASSEMBLY
// ============================================================================

module base() {

    // --- Board positions (centers, relative to enclosure center) ---
    // Relay module: along top edge of interior (positive Y), centered on X
    relay_cx = 0;
    relay_cy = (interior_w / 2) - board_gap - relay_w / 2;

    // Freenove: below relay, centered-left on X
    freenove_cx = -(interior_l / 2 - board_gap - freenove_l / 2);
    freenove_cy = -(interior_w / 2) + board_gap + freenove_w / 2;

    // I2C hub: in the corner gap to the right of the freenove
    i2c_cx = freenove_cx + freenove_l / 2 + board_gap + i2c_l / 2;
    i2c_cy = freenove_cy - freenove_w / 2 + i2c_w / 2;

    difference() {
        union() {
            // --- Main box (open top) ---
            rounded_box(ext_l, ext_w, ext_h_base, wall, corner_r);

            // --- Relay Module Standoffs ---
            for (dx = [-1, 1], dy = [-1, 1]) {
                translate([
                    relay_cx + dx * relay_mount_l / 2,
                    relay_cy + dy * relay_mount_w / 2,
                    wall
                ])
                    standoff(standoff_h, standoff_base_d, standoff_top_d, relay_hole_d);
            }
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

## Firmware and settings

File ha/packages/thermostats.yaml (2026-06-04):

# Virtual Thermostats - HA-native replacements for Hubitat virtual thermostats
# Uses HACS climate_template (jcwillox/hass-template-climate)
# Temperature from Ecowitt GW1000 sensors, setpoints in input_number helpers
#
# Single setpoint mode: shows heat setpoint in HEAT, cool setpoint in COOL.
# Global input_select.hvac_mode drives which mode/setpoint is active.

input_boolean:
  circ_optout_ben:
    name: "Ben Circulation Opt-out"
    icon: mdi:fan-off

  circ_optout_gene:
    name: "Gene Circulation Opt-out"
    icon: mdi:fan-off

  circ_optout_mbr:
    name: "MBR Circulation Opt-out"
    icon: mdi:fan-off

  circ_optout_first_floor:
    name: "First Floor Circulation Opt-out"
    icon: mdi:fan-off

input_number:
  gene_heat_setpoint:
    name: "Gene Heat Setpoint"
    min: 50
    max: 90
    step: 1
    unit_of_measurement: "°F"
    icon: mdi:thermometer-chevron-up

  gene_cool_setpoint:
    name: "Gene Cool Setpoint"
    min: 50
    max: 90
    step: 1
    unit_of_measurement: "°F"
    icon: mdi:thermometer-chevron-down

  ben_heat_setpoint:
    name: "Ben Heat Setpoint"
    min: 50
    max: 90
    step: 1
    unit_of_measurement: "°F"
    icon: mdi:thermometer-chevron-up

  ben_cool_setpoint:
    name: "Ben Cool Setpoint"
    min: 50
    max: 90
    step: 1
    unit_of_measurement: "°F"
    icon: mdi:thermometer-chevron-down

  mbr_heat_setpoint:
    name: "MBR Heat Setpoint"
    min: 50
    max: 90
    step: 1
    unit_of_measurement: "°F"
    icon: mdi:thermometer-chevron-up

  mbr_cool_setpoint:
    name: "MBR Cool Setpoint"
    min: 50
    max: 90
    step: 1
    unit_of_measurement: "°F"
    icon: mdi:thermometer-chevron-down

  first_floor_heat_setpoint:
    name: "First Floor Heat Setpoint"
    min: 50
    max: 90
    step: 1
    unit_of_measurement: "°F"
    icon: mdi:thermometer-chevron-up

  first_floor_cool_setpoint:
    name: "First Floor Cool Setpoint"
    min: 50
    max: 90
    step: 1
    unit_of_measurement: "°F"
    icon: mdi:thermometer-chevron-down

climate:
  - platform: climate_template
    name: "Gene's Room"
    unique_id: gene_thermostat
    precision: 0.1
    hvac_modes:
      - "heat"
      - "cool"
      - "off"
    min_temp: 50
    max_temp: 90
    temp_step: 1

    current_temperature_template: "{{ states('sensor.gw1000_temp_ch6') | float(0) }}"

    # Single setpoint — switches between heat/cool based on global HVAC mode
    target_temperature_template: >-
      {% if states('input_select.hvac_mode') == 'COOL' %}
        {{ states('input_number.gene_cool_setpoint') | float(76) }}
      {% else %}
        {{ states('input_number.gene_heat_setpoint') | float(62) }}
      {% endif %}

    hvac_mode_template: >-
      {% set mode = states('input_select.hvac_mode') %}
      {% if mode == 'HEAT' %}heat{% elif mode == 'COOL' %}cool{% else %}off{% endif %}

    hvac_action_template: >-
      {% set mode = states('input_select.hvac_mode') %}
      {% set temp = states('sensor.gw1000_temp_ch6') | float(0) %}
      {% set heat_sp = states('input_number.gene_heat_setpoint') | float(62) %}
      {% set cool_sp = states('input_number.gene_cool_setpoint') | float(76) %}
      {% set zs = state_attr('sensor.keenect_vent_gene', 'zone_state') | default('IDLE') %}
      {% if mode == 'HEAT' and (temp < heat_sp or zs == 'HEATING') %}heating
      {% elif mode == 'COOL' and (temp > cool_sp or zs == 'COOLING') %}cooling
      {% else %}idle{% endif %}

    set_temperature:
      - service: input_number.set_value
        target:
          entity_id: >-
            {% if states('input_select.hvac_mode') == 'COOL' %}
              input_number.gene_cool_setpoint
            {% else %}
              input_number.gene_heat_setpoint
            {% endif %}
        data:
          value: "{{ temperature | round(0) | int }}"

    set_hvac_mode:
      - service: input_select.select_option
        target:
          entity_id: input_select.hvac_mode
        data:
          option: >-
            {% if hvac_mode == 'heat' %}HEAT{% elif hvac_mode == 'cool' %}COOL{% else %}OFF{% endif %}

  - platform: climate_template
    name: "Ben's Room"
    unique_id: ben_thermostat
    precision: 0.1
    hvac_modes:
      - "heat"
      - "cool"
      - "off"
    min_temp: 50
    max_temp: 90
    temp_step: 1

    current_temperature_template: "{{ states('sensor.gw1000_temp_ch7') | float(0) }}"

    target_temperature_template: >-
      {% if states('input_select.hvac_mode') == 'COOL' %}
        {{ states('input_number.ben_cool_setpoint') | float(76) }}
      {% else %}
        {{ states('input_number.ben_heat_setpoint') | float(62) }}
      {% endif %}

    hvac_mode_template: >-
      {% set mode = states('input_select.hvac_mode') %}
      {% if mode == 'HEAT' %}heat{% elif mode == 'COOL' %}cool{% else %}off{% endif %}
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

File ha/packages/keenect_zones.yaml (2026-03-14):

# keenect_zones.yaml
# Home Assistant package: GUI-based keenect zone configuration helpers
# 4 active zone slots (zone_1 through zone_4)
# 4 passive zone slots (passive_1 through passive_4)
# input_select options are populated by pyscript on startup

input_boolean:

  # --- Active Zone Enabled ---
  keenect_zone_1_enabled:
    name: "Zone 1 Enabled"
    icon: mdi:check-circle
    initial: true

  keenect_zone_2_enabled:
    name: "Zone 2 Enabled"
    icon: mdi:check-circle
    initial: true

  keenect_zone_3_enabled:
    name: "Zone 3 Enabled"
    icon: mdi:check-circle
    initial: true

  keenect_zone_4_enabled:
    name: "Zone 4 Enabled"
    icon: mdi:check-circle
    initial: true

  # --- Passive Zone Enabled ---
  keenect_passive_1_enabled:
    name: "Passive Zone 1 Enabled"
    icon: mdi:check-circle
    initial: true

  keenect_passive_2_enabled:
    name: "Passive Zone 2 Enabled"
    icon: mdi:check-circle
    initial: true

  keenect_passive_3_enabled:
    name: "Passive Zone 3 Enabled"
    icon: mdi:check-circle
    initial: true

  keenect_passive_4_enabled:
    name: "Passive Zone 4 Enabled"
    icon: mdi:check-circle
    initial: true

input_button:
  keenect_apply_config:
    name: "Apply Keenect Config"
    icon: mdi:check-all


input_text:

  # --- Active Zone Names ---
  keenect_zone_1_name:
    name: "Zone 1 Name"
    max: 40
    icon: mdi:label
    initial: "ben"

  keenect_zone_2_name:
    name: "Zone 2 Name"
    max: 40
    icon: mdi:label
    initial: "gene"

  keenect_zone_3_name:
    name: "Zone 3 Name"
    max: 40
    icon: mdi:label
    initial: "mbr"

  keenect_zone_4_name:
    name: "Zone 4 Name"
    max: 40
    icon: mdi:label
    initial: "first_floor"

  # --- Passive Zone Names ---
  keenect_passive_1_name:
    name: "Passive Zone 1 Name"
    max: 40
    icon: mdi:label
    initial: "master_bath"

  keenect_passive_2_name:
    name: "Passive Zone 2 Name"
    max: 40
    icon: mdi:label
    initial: "office"

  keenect_passive_3_name:
    name: "Passive Zone 3 Name"
    max: 40
    icon: mdi:label
    initial: "basement"

  keenect_passive_4_name:
    name: "Passive Zone 4 Name"
    max: 40
    icon: mdi:label
    initial: "guest_bedroom"

  # --- Persistence (hidden backing store for input_select survival across restarts) ---
  keenect_zone_1_persist:
    name: "Zone 1 Config Persist"
    max: 255
    icon: mdi:content-save
  keenect_zone_2_persist:
    name: "Zone 2 Config Persist"
    max: 255
    icon: mdi:content-save
  keenect_zone_3_persist:
    name: "Zone 3 Config Persist"
    max: 255
    icon: mdi:content-save
  keenect_zone_4_persist:
    name: "Zone 4 Config Persist"
    max: 255
    icon: mdi:content-save
  keenect_passive_1_persist:
    name: "Passive 1 Config Persist"
    max: 255
    icon: mdi:content-save
  keenect_passive_2_persist:
    name: "Passive 2 Config Persist"
    max: 255
    icon: mdi:content-save
  keenect_passive_3_persist:
    name: "Passive 3 Config Persist"
    max: 255
    icon: mdi:content-save
  keenect_passive_4_persist:
    name: "Passive 4 Config Persist"
    max: 255
    icon: mdi:content-save


input_select:

  # --- Zone 1 (ben) ---
  keenect_zone_1_temp_sensor:
    name: "Zone 1 Temp Sensor"
    options:
      - "(none)"
    icon: mdi:thermometer

  keenect_zone_1_thermostat:
    name: "Zone 1 Thermostat"
    options:
      - "(none)"
    icon: mdi:thermostat

  keenect_zone_1_vent_1:
    name: "Zone 1 Vent 1"
    options:
      - "(none)"
    icon: mdi:air-filter

  keenect_zone_1_vent_2:
    name: "Zone 1 Vent 2"
    options:
      - "(none)"
    icon: mdi:air-filter

  keenect_zone_1_vent_type:
    name: "Zone 1 Vent Type"
    options:
      - light
      - number
    icon: mdi:format-list-bulleted
    initial: light

  keenect_zone_1_vent_control:
    name: "Zone 1 Vent Control"
    options:
      - Aggressive
      - Proportional
    icon: mdi:tune
    initial: Aggressive

  # --- Zone 2 (gene) ---
  keenect_zone_2_temp_sensor:
    name: "Zone 2 Temp Sensor"
    options:
      - "(none)"
    icon: mdi:thermometer

  keenect_zone_2_thermostat:
    name: "Zone 2 Thermostat"
    options:
      - "(none)"
    icon: mdi:thermostat

  keenect_zone_2_vent_1:
    name: "Zone 2 Vent 1"
    options:
      - "(none)"
    icon: mdi:air-filter

  keenect_zone_2_vent_2:
    name: "Zone 2 Vent 2"
    options:
      - "(none)"
    icon: mdi:air-filter

  keenect_zone_2_vent_type:
    name: "Zone 2 Vent Type"
    options:
      - light
      - number
    icon: mdi:format-list-bulleted
    initial: light

  keenect_zone_2_vent_control:
    name: "Zone 2 Vent Control"
    options:
      - Aggressive
      - Proportional
    icon: mdi:tune
    initial: Aggressive

  # --- Zone 3 (mbr) ---
  keenect_zone_3_temp_sensor:
    name: "Zone 3 Temp Sensor"
    options:
      - "(none)"
    icon: mdi:thermometer

  keenect_zone_3_thermostat:
    name: "Zone 3 Thermostat"
    options:
      - "(none)"
    icon: mdi:thermostat
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

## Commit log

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2026-02-11 Fix dashboard entity errors: use climate attributes instead of disabled sensors
    The Hubitat integration disables heatingsetpoint and thermostatoperatingstate
    sensor entities by default since climate entities already expose this data.
    Rewrote pyscript and dashboard to read current_temperature, temperature,
    hvac_action directly from climate entity attributes.
    [keenect.yaml]
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2026-02-11 Fix critical bugs: use light entities for Keen vents, harden against crashes
    - Switch Keen vents from cover.keen_* to light.keen_* entities (cover only
    supports open/close, not set_position — all vent commands were silently
    failing)
    - Reset hvac_on on startup to force re-arm (restored state skipped
    _hvac_turn_on since it thought furnace was already running)
    - Wrap all 9 trigger functions in try/except to prevent permanent trigger
    death from transient exceptions
    - Guard _get_climate_attr against unavailable entities returning None
    - Fix blocking I/O: use task.executor for urllib calls, task.sleep for delays
    - Fix pyscript generator expressions (use list comprehensions)
    - Fix operato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
    [keenect.yaml]
2026-02-11 Add HVAC history graphs and MBR pressure sensors to dashboard
    New History tab with 24h graphs for HVAC state (heating/cooling cycles),
    zone temperatures (all 4 zones + outdoor), and vent positions. Also adds
    missing MBR vent pressure sensors to Overview tab.
    [keenect.yaml]
2026-02-12 Migrate 1st floor servo to ESPHome native API
    ESPHome config updated for ESP32-S3 (HiLetgo WiFi Kit V3): new board,
    esp-idf framework, SH1106 display, GPIO46 servo, 400kHz I2C, boot-to-zero,
    removed web_server for memory, moved secrets to !secret refs.
    Pyscript v1.4.0: replaced HTTP POST servo control with native HA
    number.set_value() calls, vent level clamped to zone max, status reads
    actual entity state instead of commanded value.
    [hvac-1st-floor.yaml]
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2026-02-12 Add OLED screensaver to 1st floor servo controller
    Show full info 5s every 30s, otherwise display angle at random
    positions to prevent OLED burn-in. Display refresh increased to 2s
    for responsive mode transitions.
    [hvac-1st-floor.yaml]
2026-02-12 Migrate all zones to HA-native thermostats, add per-zone circulation opt-out
    Replace Hubitat virtual thermostats with HA climate_template for Ben, MBR,
    and First Floor (Gene was already migrated). Add input_boolean helpers for
    per-zone circulation opt-out controllable from dashboard cards. Pyscript
    updated to v1.7.0 with vent verification/retry, circulation-aware startup,
    and dynamic opt-out checks.
    [keenect.yaml, thermostats.yaml]
2026-02-13 Keenect v2.2.0: cost tracking, aggressive vents, thermostat precision fixes
    - Add HVAC runtime and heating cost tracking (Lennox G61MPV, DTE gas)
    with daily/monthly utility_meter tallies and dashboard cost section
    - Switch all zones to Aggressive vent control for shorter furnace runs
    - Set 15% minimum vent opening while actively heating (prevents dead air)
    - Fix dedup gate skipping close-to-zero commands (servo stuck at 9%)
    - Close all vents on startup when system is idle (prevent stale positions)
    - Add precision: 0.1 to climate_template (show true temp, not rounded)
    - Fix hvac_action_template to reflect pyscript zone_state during hysteresis
    - Restore setpoint log from sensor attributes on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
    [hvac-controller.yaml]
2026-02-13 Keenect v2.3.0: cooling cost tracking, code review fixes
    - Add cooling cost calculation (AC wattage x hours x $/kWh)
    - Add input_number helpers: ac_wattage (3500W), electric_price_per_kwh ($0.19)
    - Add sensor.hvac_cool_cost + daily/monthly utility_meters
    - Add cooling cost and AC settings to dashboard
    - Fix _set_vent using heat_max_vo regardless of HVAC mode
    - Remove unused ok variable in _hvac_turn_on
    - Simplify redundant outdoor temp check in _update_status
    - Remove dead retry_count from state dict
    - Add gas price auto-update (weekly scrape of MI comparison site)
    [keenect.yaml]
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2026-02-13 Fix activity log formatting and user identification
    Add dot separator between zone and type in setpoint log display.
    Resolve HA user IDs to friendly names via auth user cache instead of
    showing raw hex IDs for accounts without person entities.
    [keenect.yaml]
2026-02-13 Fix activity log: line breaks between entries, integer temps
    Switch dashboard markdown template from >- (folded-strip) to > with
    blank lines so each setpoint entry renders on its own line. Add | int
    filter to strip .0 from whole-number temperatures. Store setpoint
    values as int in pyscript when they are whole numbers.
    [keenect.yaml]
2026-02-13 Keenect v2.4.0: anomaly detection via InfluxDB temperature trends
    Query InfluxDB for 30-min temperature history every 10 minutes. When
    HVAC is active and a zone's temp moves >1°F in the wrong direction
    (dropping while heating, rising while cooling), flag it as an anomaly
    with a persistent notification. Catches stuck vents, open windows, or
    equipment issues. Dashboard shows anomaly sensor in HVAC Control section.
    [keenect.yaml]
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2026-02-13 Drift rate analysis, away thermostat sync, startup away enforcement
    Drift analysis: query InfluxDB for natural heat loss rates per zone,
    normalized by indoor-outdoor temperature difference. First floor is
    leakiest (17.3), Gene's room best insulated (6.6). Foldable dashboard
    section shows per-zone drift with Leakiest/High/Good labels.
    Away mode: add state_trigger handler that actually changes thermostat
    input_number setpoints when away is toggled (so thermostat cards show
    correct values). Startup enforces away setpoints for already-away zones.
    Saves/restores original setpoints with zone defaults as fallback.
    [keenect.yaml]
2026-02-13 Show overnight temp drop instead of raw drift rate, fix drift labeling and away restore
    - Drift sensors now show practical "~X°F/night" based on current indoor/outdoor temps
    - Fix drift labeling: compare against average (not worst zone) for High threshold
    - Fix away restore falsy check: use `is not None` to handle theoretical zero values
    - Skip startup away setpoint writes when values already match (prevents spurious logs)
    - Rename dashboard section "Drift (Insulation)" → "Overnight Heat Loss"
    [keenect.yaml]
2026-02-13 Round HomeKit setpoints to integers, add thermostat +/- buttons, history cost graphs
    - thermostats.yaml: round set_temperature values with | round(0) | int (fixes
    Apple Home Celsius conversion producing non-integer Fahrenheit like 64.94)
    - Dashboard: add features: target-temperature to restore +/- buttons on thermostat cards
    - Dashboard: add Daily Heating and Daily Cooling history graphs (7-day view)
    - Pyscript: use tolerance-based setpoint comparison to filter float jitter on reload
    [keenect.yaml, thermostats.yaml]
2026-02-15 Add RGB status LED to ESPHome controller, warmup vent delay on cycle start
    ESPHome: onboard WS2812 LED on GPIO48 shows red=heating, blue=cooling,
    green=idle, flashing yellow=watchdog error, alternating yellow/blue=bypass.
    Keenect: vents now held at minimum opening during HVAC warmup to avoid
    blowing unconditioned air. Uses supply/return duct temp delta from ESPHome
    sensors when available, falls back to 120s fixed delay if sensors offline.
    [hvac-controller.yaml]
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2026-02-17 ESPHome controller: fix relay GPIO inversion, add web/MQTT, working RGB status LED
    - Add inverted: true to all 7 relay GPIOs (active-low relay board)
    - Add GPIO18 spare relay switch to prevent floating pin
    - Add web_server v3 on port 80 and MQTT broker connection
    - Remove deprecated rmt_channel, use direct pixel addressing for RGB LED
    - Status LED colors: green=idle, red=heat, blue=cool, purple=bypass, orange flash=error
    - Passed 100-cycle torture test: 3806 requests, 0 failures, no memory leaks
    [hvac-controller.yaml]
2026-02-17 Add MQTT mirror mode for parallel testing with Flask controller
    ESPHome controller:
    - Add mirror mode: subscribes to hvac/mirror/command MQTT topic
    and shadows Flask relay states without controlling the furnace
    - Fan and UV auto-follow heat/cool (on together, off together)
    - Publish ESPHome state to hvac/mirror/esphome every 30s for comparison
    - Mirror mode prevents on_client_connected from exiting bypass
    HA integration:
    - Add hvac_mirror.yaml package with comparison sensors
    (flask command vs esphome state, mismatch binary sensor)
    - Add Mirror Test tab to HVAC dashboard with status and history graph
    [hvac-controller.yaml]
2026-02-17 ESPHome: add memory monitoring, VOC improvements, and OLED enhancements
    - Add free heap/PSRAM sensors (HA diagnostic entities)
    - Auto-reboot on critical low memory (<15kB), warnings at 30/60kB
    - MQTT memory reporting to hvac/memory every 60s
    - VOC display: human-readable Good/Moderate/Poor instead of raw kOhm
    - BME680 burn-in filter: skip first 5min of VOC readings after boot
    - OLED: heap on status page, supply/return temp delta on sensor page
    - Fix VOC unit_of_measurement to kΩ (was defaulting to Ω)
    [hvac-controller.yaml]
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2026-02-24 Pyscript safety hardening + drift analysis fix
    - Push failure cascade: notification at 3 fails, auto-disable at 5
    - Short-cycle protection: 120s heat, 300s cool minimum off time
    - Min-run enforcement: 180s before allowing turn-off
    - Sensor death alerting: notification at 3 Nones, vents to neutral at 10, emergency shutoff if all dead
    - Startup fix: safety sync before eval, try/finally guard, 90s Zigbee delay
    - Cost tracking persistence (hr/hc/cr/cc) with 255-char fallback
    - Warmup sensor staleness tracking + status attribute
    - MQTT heartbeat publisher (60s) for ESPHome watchdog
    - Drift analysis: tighten filter 0.15→0.08, use p25 instead of median
    - Dashboard: show all 8 zones in overnight h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
    [keenect.yaml]
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2026-02-25 ESPHome: safety hardening for standalone controller operation
    - Short-cycle relay protection: 120s heat, 300s cool minimum off time
    - Max-run timer: force off + bypass after 2h continuous operation
    - Supply temp limits: >160F emergency shutoff, <80F after 10min warning
    - Overpressure detection: >10 hPa pressure delta forces off + bypass
    - MQTT heartbeat subscriber: bypass mode if no keenect heartbeat for 5min
    - API watchdog: reduced from disabled to 15min reboot timeout
    - Changeover relay settle: 200ms delays between relay activations
    [hvac-controller.yaml]
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2026-03-14 GUI zone config + sensor swap fix
    - Fix swapped ch4/ch7 sensors for Ben/MBR zones (thermostats.yaml + keenect_ha.py)
    - Add GUI-based zone configuration via HA input helpers (keenect_zones.yaml)
    - 4 active zone slots + 4 passive zone slots with dropdown entity pickers
    - Pyscript auto-populates dropdowns from available HA entities on startup
    - input_text backing store for restart survival of input_select values
    - input_button Apply Config trigger with runtime state reconciliation
    - Migration service (pyscript.keenect_migrate_config) for initial setup
    - Dashboard: add Config tab, fix History tab sensor labels, fix fold-entity-row
    timing issue with section-based heads for learning/dr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
    [keenect.yaml, keenect_zones.yaml, thermostats.yaml]
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2026-03-14 Fix gas rate: use gas_rate_per_therm ($0.9565 all-in) not gas_price_per_therm ($0.472 tariff-only)
    Also update FURNACE_BTU_DEFAULT from 60000 to 82400 (G61MPV runs ~80% high fire).
    Keenect tracks runtime, energy project derives accurate cost from it.
    [keenect.yaml]
2026-03-14 Fix electric rate: use sensor.current_electric_rate from energy project
    The old input_number.electric_price_per_kwh no longer exists — energy
    project centralized rates into sensor.current_electric_rate ($0.2053/kWh).
    [keenect.yaml]
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2026-04-07 Prepare for public release: documentation, repo cleanup, and bug fix
    - Add comprehensive README.md with architecture, BOM, installation guide, and safety docs
    - Add docs/hardware.md with GPIO pin maps, wiring diagrams, and bypass architecture
    - Add MIT LICENSE
    - Add esphome/secrets.yaml.example template
    - Move Hubitat Groovy files to hubitat/ directory (legacy, historical reference)
    - Move MQTT broker IP to secrets.yaml in ESPHome config
    - Add static IP configuration comments in ESPHome configs
    - Fix _verify_vents: force-close vents that reconnect open during IDLE
    - Add check_drift.py temperature sensor drift analysis tool
    - Add dashboard screenshots
    - Update .gitignore to exclude logs/
    [hvac-controller.yaml]
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2026-05-26 Kindle dashboard: HA-weather port + text-based barometer panel
    Kindle wall display (jailbroken K4NT showing a Puppeteer-rendered HA dashboard)
    got a full e-ink redesign that mirrors the structure of the HA weather dashboard
    while keeping the existing serif/mono aesthetic.
    ha/dashboards/kindle.yaml — full rewrite (backup at kindle.yaml.bak.20260524):
    - Hero: big serif outdoor temp + condition icon + italic phrase ("Mild &
    comfortable, a light breeze · SUNNY")
    - 4-tile stat row: Wind rose (small SVG, rotating arrow) | Outdoor T/RH +
    dewpoint | Pressure + trend arrow | Today's rain
    - Indoor + dewpoint-aware window suggestion ("Open / Keep closed / No comfort
    gain") computed inline via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
    [weather.yaml]
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2026-06-04 thermostats: rename modes -> hvac_modes for climate_template v0.7.6
    HA 2026.6 broke the abandoned jcwillox/hass-template-climate (v1.3.0):
    the legacy platform: setup path now creates zero entities, leaving all
    4 zone thermostats restored/unavailable. Migrated to the maintained
    fork litinoveweedle/hass-template-climate v0.7.6 (HA 2026.6 compatible),
    installed + tracked via HACS. That fork renamed the climate_template
    config key modes: -> hvac_modes:, so update thermostats.yaml to match
    the deployed config and prevent a future redeploy from re-breaking it.
    [thermostats.yaml]
2026-06-04 weather/kindle dashboards: show 'calm' at 0 mph instead of unavailable wind
    The WeeWX AcuRite vane reports no wind direction when calm, so
    sensor.weewx_wind_direction goes unavailable at 0 mph (by design via its
    availability template). The wind tiles read that sensor unconditionally
    and rendered 'unavailable'/NaN. Add a calm guard (speed < 0.5) that shows
    'calm'/'CALM' and skips the direction lookup, so the tile stays clean
    whether or not the direction sensor is available.
    [weather.yaml]
2026-06-04 weather: dedup duplicate WeeWX sensor layers, consolidate on canonical entities
    HA had 3 overlapping WeeWX weather sensor layers: an old rest: poller and
    an old mqtt: sensor block (both in deployed configuration.yaml, no unique_ids)
    duplicating the canonical weewx_sensors.yaml package and forcing _2/_3 suffixes
    via entity-id collisions. Removed the rest:, mqtt: weather, and dead
    weather: - platform: template blocks from the deployed configuration.yaml
    (not repo-tracked) and consolidated on the canonical unique_id'd entities.
    Repo changes supporting that cleanup:
    - weewx_sensors.yaml: add canonical sensor.weewx_barometer_trend_3h (statistics
    sensor off weewx_barometer_2) to replace the RES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
    [keenect.yaml]
2026-06-06 weather: add weekly/monthly rain accumulation counters
    Add rain_accumulation.yaml package: an MQTT sensor for WeeWX's monotonic
    hardware rain counter (rain_total) plus two utility_meters (weekly +
    monthly cycles) -> sensor.rain_this_week / sensor.rain_this_month. WeeWX's
    AcuRite driver doesn't publish week/month aggregates, so utility_meter on
    the monotonic total is the accurate approach; meters were calibrated to the
    WeeWX DB period-to-date totals (~0.59 in) at deploy so they're correct
    immediately rather than starting from zero.
    Fold the wk/mo totals into the existing Weather dashboard Rainfall tile
    subtitle (no layout change). weather-now is yaml-mode -> dashboards/weather.yaml.
    [weather.yaml]
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2026-06-07 weather/kindle: window advisor = open-vs-AC vs hottest room
    Fix two problems with the window recommendation:
    1. AC enabled no longer forces 'keep closed'. The recommendation is now
    condition-driven (open vs run AC); HVAC mode only affects wording and the
    HEAT case. Cooler+drier outside than the room -> 'Open windows — skip the
    AC' even while cooling; only says run-AC/closed when outdoor air is
    genuinely warmer or more humid.
    2. Compare against the HOTTEST of the 4 conditioned rooms (each room's own
    temp + humidity for its dewpoint) instead of a single console sensor, since
    the warmest room is what drives the AC. Subtitle names the room used.
    Implemented in both weather.y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
    [weather.yaml]
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2026-06-08 weather/kindle: window advisor only suggests AC when there's cooling demand
    Bug: the advisor said 'Run the AC' even when the hottest room was already
    below its cool setpoint (no demand — AC isn't running). Now it reads the
    hottest room's setpoint (its climate entity 'temperature' attr) and:
    - COOL + demand (room >= setpoint): open-vs-AC logic as before
    - COOL + no demand (room < setpoint): fresh-air/comfort wording, never 'Run the AC'
    ('Open for fresh air' / 'Keep closed — already comfortable')
    - HEAT: keep closed; OFF: corrected 4-way dewpoint logic
    Subtitle shows hottest room, its setpoint, dewpoints, and AC cooling/idle.
    [weather.yaml]
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2026-06-09 irrigation: add ET-based lawn + planter watering advisor
    New pyscript irrigation_advisor.py + irrigation.yaml package + a panel on the
    Weather dashboard. No solar sensor exists (AcuRite Iris 5-in-1 has none / WeeWX
    ET is NULL), so it uses temperature-based Hargreaves-Samani ET0 from
    weather.forecast_home daily Tmax/Tmin + computed extraterrestrial radiation
    (lat 42.97N), with a humidity correction for the humid MI climate.
    Lawn: clay soil-water-balance bucket (Kc 0.80, 6in root zone, AWC 1.5in/ft,
    MAD 50% -> 0.375in trigger, ~1.0in target). Daily rain via the monotonic
    weewx_rain_total delta with a clay runoff cap; recommends a deep watering with
    a run-time estimate (tunable input_number.ir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
    [weather.yaml]
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2026-06-24 hvac-controller: return BME680 via Bosch BSEC2 — IAQ / VOC-eq / CO2-eq
    - Swap plain bme680 driver for bme68x_bsec2 (ESP32-S3 needs BSEC2, not BSEC1)
    - Adds Return IAQ, Breath VOC (ppm), CO2 equivalent (ppm), IAQ accuracy/status
    - Keeps return_temp/hum/pres/voc ids so existing deltas keep working
    - temperature_offset 0.37 °C compensates BSEC LP-mode self-heating (re-zeros deltas)
    - IAQ self-calibrates over hours/days (accuracy 0->3); provisional until accuracy >=2
    [hvac-controller.yaml]
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2026-06-24 air-quality: human-readable Return Air Quality sensor + IAQ confidence on dashboard
    - New template sensor sensor.return_air_quality: state = plain-English Bosch IAQ
    rating (Excellent..Extremely polluted); binds raw iaq, accuracy (0-3), status,
    reliable (accuracy>=2), CO2-eq and VOC-eq ppm as attributes so the rating never
    travels without its confidence
    - Dashboard: IAQ card overlays accuracy on a secondary axis; new entities card
    shows the plain-English rating + IAQ + BSEC confidence + CO2/VOC at top of the
    Controller tab
    [keenect.yaml]
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2026-06-24 hvac: differential-pressure filter-loading monitor
    Measures supply-return ΔP during the fixed-airflow circulation windows (filter is
    bracketed by the two pressure sensors), smooths with an EMA, and compares to a
    clean-filter baseline:
    - sensor.filter_dp_circulation (EMA, CIRCULATING-only; no device_class so HA keeps
    it in hPa instead of converting a pressure device_class to imperial psi)
    - sensor.filter_loading (% of baseline)
    - input helpers: baseline ΔP, threshold %, reset button, last-changed date
    - automations: capture baseline on button press; alert when loading > threshold 30m
    - dashboard: Filter Monitor entities card + 7-day ΔP trend on the Controller tab
    Press Reset Filter Basel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
    [keenect.yaml]
2026-06-28 hvac-controller: fix short-cycle guard livelock (cool + heat)
    The short-cycle protection re-armed its own timer on every BLOCKED
    turn-on: a blocked on_turn_on called *_sw.turn_off(), whose on_turn_off
    unconditionally stamped *_last_off = millis(). With keenect re-requesting
    the relay every 60s, each block reset the 300s/120s window, so it never
    elapsed and the compressor/heat could never engage (silent no-AC for 33h;
    heat had the same latent bug at 120s).
    Only stamp *_last_off on a genuine run->off transition by gating on the
    existing *_on_since sentinel (set only when the guard passes). Blocked
    attempts and the boot-time ALWAYS_OFF leave *_on_since == 0, so they no
    longer re-arm the timer.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
    [hvac-controller.yaml]
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2026-06-28 hvac: circulation mode selector (Off / Periodic / Continuous)
    The periodic-circulation automation toggled enable_circulation ON at :00
    and OFF at :10 unconditionally, so a manual continuous circulation got
    chopped off every hour at :10. Replace the always-on behavior with an
    input_select.circulation_mode (Off/Periodic/Continuous):
    - Continuous: holds enable_circulation on; periodic automation is inert.
    - Periodic: the :00/:10 automation runs (now gated on mode=='Periodic').
    - Off: enable_circulation off.
    A mode-controller automation drives enable_circulation from the selector;
    keenect is unchanged (still reads enable_circulation). Dashboard gains the
    selector in System Settings.
    [keenect.yaml]
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2026-06-29 hvac-controller: pre-heat-wave safety (max-run cooldown-and-resume, coil-freeze cutout, heartbeat watchdog)
    Pearl backup thermostat is OFF, so bypass = no conditioning. Recoverable
    conditions must never latch bypass:
    - Max-run (cool + heat): raised ceiling 2h->4h and replaced turn_off+bypass
    with a 10-min cooldown window + an on_turn_on cooldown guard. Auto-resumes
    via the 60s keenect heartbeat. No bypass. (This was tonight's failure.)
    - Coil-freeze cutout during COOL: supply <3.3C (38F) sustained 180s -> cool
    off, fan+UV held on to thaw, lockout until supply >7.2C (45F). Recoverable,
    no bypass. (Cooling had zero coil-freeze protection before.)
    - H2: seed last_heartbeat=millis() at b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
    [hvac-controller.yaml]
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2026-06-29 hvac: pre-heat-wave LOW-severity audit fixes (L2-L9; L1 deferred)
    keenect (keenect_ha.py):
    - L5: raw-sensor COOL-start fallback when climate_template hvac_action is
    unavailable (symmetric with the away branch).
    - L6: on_circ_optout_change now guards on hvac_on (no vent stomp mid-run).
    - L7: clear sensor_fail_parked once zones report healthy (no spurious later close).
    - L8: persist sensor_fail_parked + all_none_count across HA restart.
    - L9: _hvac_push treats a command to an unavailable ESP32 switch as a FAILURE
    so the push-fail/auto-disable fail-safe actually engages.
    firmware (hvac-controller.yaml):
    - L3: fan/UV turn-on moved inside the on_turn_on lambdas (after the guards) so
    a shor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
    [hvac-controller.yaml]
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
